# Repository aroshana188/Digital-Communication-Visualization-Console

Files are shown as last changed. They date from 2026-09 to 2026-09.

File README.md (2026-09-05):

# Digital Communication Visualization Console





*An interactive embedded hardware instrument engineered to visually map and demonstrate the fundamental mathematical abstractions of digital communication pipelines.*

<p align="center">
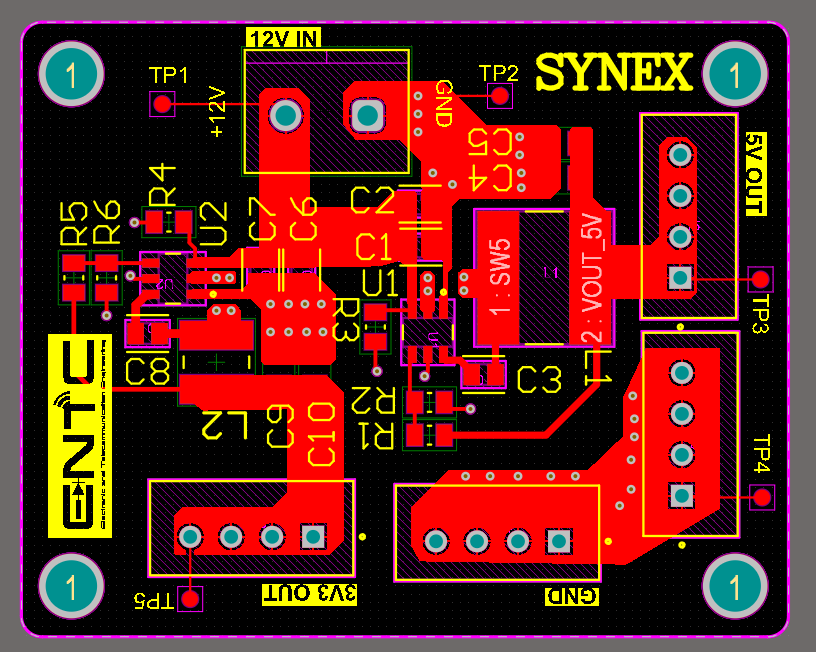
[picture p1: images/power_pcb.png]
  
</p>

---

## 📋 Project Overview
Developed by Team SyneX for the EN2160 Electronic Design Realization module, this desktop console solves a critical pedagogical gap in undergraduate telecommunication engineering. It provides a real-time, tactile hardware verification loop for abstract mathematical concepts like entropy reductions, cyclic redundancy protections, and complex constellation mappings.

Processing a user-defined alphabet set, the STM32-driven console dynamically renders multi-stage transformations—from Source Coding and Packetization to Channel Coding and Digital Modulation—directly onto dual 3.5" TFT panels and LED monitoring arrays.

---

## 🛠️ My Engineering & Business Contributions
As a core member of Team SyneX, I took ownership of the following technical and commercial domains:

### 1. Power Architecture & PCB Design
* **Dual-Buck Converter PCB:** Designed a dedicated power distribution PCB utilizing switching-mode buck converters to efficiently step down a 12V DC input to a stable 5V rail (for TFT displays/LEDs) and a clean 3.3V rail (for the STM32 logic).
* **Signal Integrity:** Implemented strict isolation strategies on a double-sided FR4 PCB, restricting high-speed SPI data traces to the top copper layer while isolating sensitive analog noise-simulation routing on the bottom layer, anchored by a solid ground pour to prevent EMI.

### 2. Mechanical Engineering & Enclosure CAD
* **Parametric Modeling:** Engineered the mechanical enclosure using SolidWorks, adopting a top-down assembly methodology. 
* **Ergonomics & Fabrication:** Designed optimized, reflection-free display mount angles for collaborative laboratory viewing. Integrated specialized internal mounting bosses for the PCBs and utilized equation-driven global variables to ensure dimensional coherence for eventual injection-molding scalability.

### 3. User Interface (UI) Architecture
* **Dual-Display Logic:** Contributed to the interface formatting layout across the twin 3.5" SPI TFT panels.
* **Tactile Integration:** Mapped the interface to allow users to input character strings via a 4x4 matrix keypad and visualize real-time bit error rate (BER) transformations dynamically controlled by a physical analog linear potentiometer.

### 4. Business Model & Market Analysis
* **Demand Forecasting:** Evaluated the Sri Lankan educational sector, identifying a potential market demand of 80 to 100 units across local universities and technical institutes.
* **Financial Procurement:** Calculated a scaled mass production budget, bringing the final market-ready cost down to LKR 25,425 per unit by strategizing bulk component sourcing and injection molding.
* **Commercialization Strategy:** Formulated a competitive B2B pricing strategy and Unique Value Proposition, positioning the console as a highly affordable, locally manufactured alternative to expensive imported telecommunication instrumentation platforms.

---

## ⚙️ System Specifications & Capabilities

### Hardware Core
* **Microcontroller:** STM32 ARM Cortex-M Series
* **Displays:** 2 x 3.5" SPI TFT Displays (320x480) driven via DMA
* **Bitstream Mapping:** 3x 74HC595 Serial-in Parallel-out Shift Register LED Arrays
* **Channel Simulation:** Analog Linear Rotational Potentiometer mapped to a 12-bit ADC

### Algorithmic Pipeline
1. **Source Coding:** Real-time generation of Fixed-Length, Huffman, and Shannon-Fano encoding trees.
2. **Packetization:** Dynamic segmentation of bitstreams into 4, 6, or 8-bit frame boundaries.
3. **Channel Coding:** Generation and verification of Parity (Even/Odd), CRC (CRC-3/CRC-4), and (7, 4) Hamming Code protection.
4. **Modulation:** Phase-mapping for ASK, BPSK, QPSK, and 16-QAM constellation rendering.

---

## 🤝 Team SyneX
This console was engineered by undergraduates at the Department of Electronic & Telecommunication Engineering, University of Moratuwa:
* **A.M.S. Ahamed**
* **H.A.P. Aroshana** *(Power PCB, Enclosure CAD, UI Design, Market Analysis)*
* **W.D.A.C. Bandara**
* **R.K.T. Dissanayake**
* **U.G.R.B. Tennakoon**

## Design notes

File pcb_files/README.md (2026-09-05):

This folder contains all circuit schematics and pcb files.

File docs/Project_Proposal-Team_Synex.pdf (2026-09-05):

# Digital Communication Visualization Console

## Project Proposal by Team Synex

Domain: Education, Telecommunications

### Problem Statement

Digital communication is a core subject in electrical and telecommunication engineering programs in Sri Lanka. However, most universities rely heavily on simulations (MAT-LAB/Python) to teach concepts such as source coding, packetization, CRC, and channel errors.
Students often understand mathematical theory but struggle to visualize:
- How variable-length coding compresses data
- How packets are formed
- How CRC bits are generated
- How noise corrupts bits
- How corrupted packets are detected and discarded

Therefore, there is a need for an affordable, locally developed, hardware-based communication system demonstrator that visually represents each stage of a digital communication chain.

### Stakeholder Analysis

Primary Stakeholders

- State universities offering Telecommunication degrees
- Private engineering institutions
- Technical and vocational training institutes
- Institutions such as University of Moratuwa and University of Peradeniya conduct communication systems laboratories where this device can be directly deployed

Secondary Stakeholders

- Lecturers who require demonstrative teaching tools
- Undergraduate students learning digital communications
- Lab coordinators managing equipment budgets

Stakeholder Insights

Stakeholders Consulted - Dr.Samiru Gayan, Senior Lecturer, Electronic and Telecommunications Department, University of Moratuwa.

During preliminary discussions with Dr. Samiru Gayan, it was highlighted that current laboratory sessions rely heavily on simulations. Although simulations are useful, they do not provide a clear physical representation of:

EN2160 - Electronic Design Realization | Team Synex
- Bitstream formation
- Packet boundaries
- Redundancy addition
- Bit corruption due to noise
- Packet rejection mechanisms

### Proposed Solution

The Digital Communication Visualization Console (DCVC) is a desktop unit that demonstrates:

- Symbol generation
- Fixed-length and Huffman source coding
- Packetization (4–8 bit packets)
- Parity and CRC error detection
- Adjustable noisy channel
- Packet validation and rejection

Users can enter short messages, observe LED-displayed codewords, divide the bitstream into small packets (4, 6, or 8 bits), add CRC/parity bits, transmit through a simulated noisy channel, and observe accepted or rejected packets.

### Technical Specifications

Parameter | Specification
Symbols | 5 (A–E)
Coding Methods | Fixed (3-bit), Huffman
Packet Sizes | 4, 6, 8 bits
Error Detection | Even/Odd Parity, CRC
CRC Divisor | 3–4 bit user input
Noise Model | Adjustable BER
Controller | ESP32
Display | 2.4” TFT LCD
Bit Visualization | 8–16 LED array
Power Supply | 5V DC

Table 1: DCVC Technical Specifications

EN2160 - Electronic Design Realization | Team Synex

### Budget Estimation

Category | Item | Total (LKR)
Microcontroller | ESP32 | 1,000
Display | 2.4” TFT LCD | 1,700
LED Arrays & Drivers | 74HC595 + LEDs | 3,500
Input Controls | Push Buttons, Encoder, DIP Switches | 2,500
Power & Regulation | 5V Supply, Regulators | 2,500
PCB Fabrication | 2-layer PCB | 5,000
Enclosure | Acrylic/ABS casing | 5,000
Miscellaneous | Wiring, Connectors, Mounting | 3,000
Estimated Total | | 24,200

Table 2: DCVC Budget Breakdown

According to this approximation, the total cost per unit is around LKR 25,000. The expected selling price could be LKR 30,000–35,000.

### Hardware and Software Complexity

The system consists of four main subsystems:

- Input Subsystem – Push buttons (A–E), probability adjustment knob, packet size selector, CRC divisor input.
- Processing Subsystem – ESP32 microcontroller implementing: Huffman tree generation, Fixed-length coding, Packetization, CRC computation, Pseudo-random noise injection.
- Visualization Subsystem – LED arrays for codewords and packet bits, TFT display for packet view.
- Control & Power Subsystem – Voltage regulation, LED driver circuits, protection components.

### Estimated Market Requirement in Sri Lanka

Estimated institutions:

- ≈10 universities with engineering programs,
- ≈20 technical institutes

Assuming:

- 4–5 units per university,
- 2–3 units per technical institute

Total potential demand ≈ 80–100 units
Estimated annual demand ≈ 15–25 units
This makes the product commercially viable within the educational sector.

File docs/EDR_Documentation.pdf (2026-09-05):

### University of Moratuwa

### Faculty of Engineering

### Department of Electronic & Telecommunication Engineering

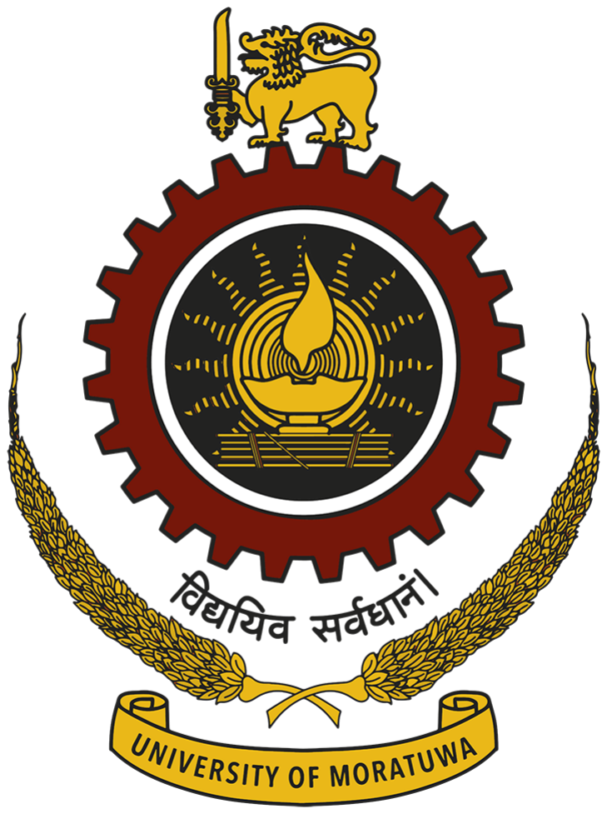
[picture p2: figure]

### EN2160: Electronic Design Realization

# Digital Communication Visualization Console

### An Interactive Embedded System for Visualizing Fundamental Concepts of Digital Communication Systems

### Team SyneX

230020R A.M.S. Ahamed
230058N H.A.P. Aroshana
230082G W.D.A.C. Bandara
230164K R.K.T. Dissanayake 230629R U.G.R.B. Tennakoon

Abstract

Abstract mathematical paradigms in telecommunication engineering, including variable-length source entropy reductions, linear block cyclic redundancy protections, and complex constellation symbol mappings, present significant pedagogical barriers in traditional undergraduate lecturing formats. This report documents the complete design realization of the Digital Communication Visualization Console by Team Synex for module EN2160. Driven by a high-performance ARM Cortex-M based STM32 microcontroller, this hardware instrument provides a localized physical verification loop for abstract concepts. Processing a user-defined alphabet set (S = {A, B, C, D, E}), the console calculates and renders multi-stage transformations—from Source Coding (Fixed-length, Huffman, Shannon-Fano) to Packetization framing configurations, Channel Coding (Parity, CRC, Hamming), and digital modulations (ASK, BPSK, QPSK, QAM). Featuring twin 3.5” SPI TFT panels managed via Direct Memory Access (DMA), dynamic 74HC595 shift reg-

ister LED monitoring arrays, and physical potentiometer-driven additive noise emulation circuits interfacing with internal 12-bit ADCs, the device allows students to visually audit transmission metrics, code-word transitions, and real-time constellation degradation.

# Contents

Digital Communication Visualization Console | University of Moratuwa
8.2 | Potentiometer Noise Calibration and Signal Profile Mapping . . . | 14
11.2 | Real-Time Bit Error Rate (BER) Graphical Plotting Engine . . . | 19

# List of Figures

1 | Global Block Interconnect Architecture and STM32 Bus Distribution . . | 6
2 | Enter Caption | | 6
3 | Enclosure Mechanical Evolution and Interface Formatting Layout . . . . | 12
4 | Central STM32 System Schematic and Bus Track Routing Breakouts . . | 13
5 | 12V to 5V and 3.3V Dual Buck Converter Power Schematic | | 13

# List of Tables

1 | Design Matrix of Architectural Implementation Alternatives | | 7
2 | System Hardware and Architectural Component Specifications | | 8
3 | Algorithmic Compression and Code-Word Length Test Matrix | | 14
4 | STM32 12-bit ADC Noise Mapping Calibration Data | | 15
5 | Itemized Component Budget for the Initial Prototype | | 16
6 | Estimated Unit Budget for Scaled Production (100–200 Units/Year) . . . | 17

### 1 Introduction

### 1.1 Background

Modern telecommunication systems rely on multi stage digital signal manipulation architectures to maximize data transfer rates, minimize operational bandwidth utilization, and defend information vectors against channel impairments. In pedagogical frameworks, these multi stage blocks are fundamentally decoupled into strict mathematical abstractions: informational entropy metrics, orthogonal phase space projections. While critical for core engineering theory, these mathematical concepts frequently present comprehension challenges for undergraduate students when separated from tactile, real time hardware manifestations.

### 1.2 Motivation

The inspiration for this design is rooted in the current educational gap within electrical and telecommunication laboratory courses in Sri Lanka. Engineering students typically evaluate communication pipelines via pure software simulation scripts (e.g., MATLAB or Python environments). Although software environments offer numerical flexibility, they

separate students from physical timing restrictions, real time clock domains, and hardware interface realities. This project establishes an interactive, intermediate educational desktop platform that delivers high fidelity visual and tactile feedback in real time.

### 1.3 Problem Statement

Digital communication is a cornerstone domain within electrical, electronic, and computer engineering curricula. However, undergraduate engineering students often master the underlying abstract mathematical frameworks while struggling to build a clear mental model of physical realization. Specifically, students struggle to visualize:

- The operational behavior and code-tree generation variations of dynamic variable-

length source compilers.

- How bitstreams are partitioned into distinct boundaries to execute packetization

workflows.

- How redundancy bits (CRC or parity) are mathematically appended to message

frames.

- The explicit mechanism by which random channel noise corrupts transmission bits.
- How corrupted packets are evaluated, flags are trigged, and bad frames are ulti-

mately rejected and discarded by receiver logic.

### 1.4 Stakeholder Analysis

To map the deployment environment effectively, a complete stakeholder analysis was executed:

- Primary Stakeholders: State and private engineering universities offering Telecom-

munication, Electronic, and Electrical Engineering degree programs (such as the University of Moratuwa and the University of Peradeniya). This also includes tech-

nical, vocational, and technological colleges where communication systems laboratories require practical instrumentation benches.

- Secondary Stakeholders: Academic lecturers and instructors who require real

time demonstrative teaching aids, undergraduate students seeking intuition beyond math equations, and lab coordinators managing tight equipment procurement budgets.

### 1.5 Stakeholder Insights & Expert Consultation

Detailed consultation loops were conducted with Dr. Samiru Gayan, Senior Lecturer within the Department of Electronic & Telecommunication Engineering at the University of Moratuwa. Dr. Gayan confirmed that current university laboratory exercises are structurally skewed toward abstract software models. He emphasized that the introduction of a localized hardware development platform would resolve critical learning bottlenecks by providing immediate visual indicators for bitstream formation, packet boundaries, redundancy additions, and hardware packet rejection behaviors.

### 1.6 Project Objectives

The system targets the following core engineering goals:

- Construct a robust, standalone laboratory instrument that processes a standard

data alphabet set (S = {A, B, C, D, E}) under user specified statistical profiles.

- Integrate a continuous software execution pipeline comprising interchangeable algo-

rithmic blocks for Source Coding, Packetization framing, Channel Error Protection, and Carrier Modulation.

- Implement a dual display SPI processing topology utilizing STM32 DMA controllers

to separate operational menu entry tracking from physical wave shape and constellation scatter layouts.

- Deploy a tactile hardware subsystem utilizing automated logic registers and analog

noise pots to show bit error rate transformations dynamically.

### 1.7 System Scope & Boundaries

The console serves strictly as a baseband and digital carrier visualization instrument for academic laboratories. The hardware boundary focuses on structural logic validation and display rendering rather than high power RF transmission over antennae arrays. All signal mutations, carrier shapes, and channel path interference distributions are mapped directly within the core microcontroller logic engine and translated to dedicated visual interfaces.

### 2 System Architecture & Engineering Alternatives

### 2.1 Global Block Interconnect Architecture

The structural framework of the system relies on a modular, decoupled signal routing layout. High level compute blocks pass operational parameters directly to localized peripheral hardware layers.

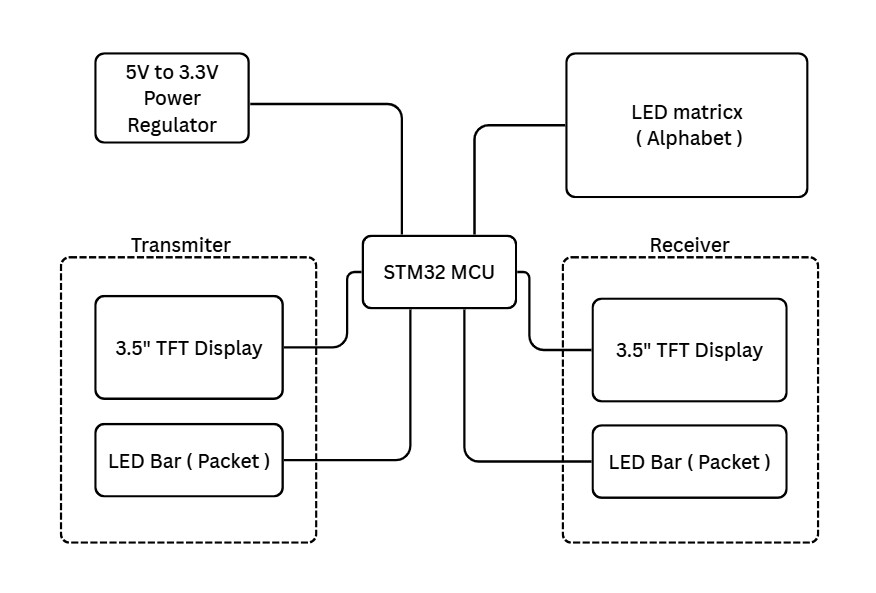
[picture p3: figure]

Figure 1: Global Block Interconnect Architecture and STM32 Bus Distribution

Figure 2: Enter Caption

### 2.2 Analysis of System Engineering Alternatives

During the conceptualization phase, three architectural implementations were evaluated. Table 1 summarizes the comparative trade offs that informed the final hardware selection.

Table 1: Design Matrix of Architectural Implementation Alternatives

Implementation
Path
Engineering Advantages | Technical Disadvantages

Pure Software
Simulation
(MATLAB /
Python)

High mathematical precision; easy implementation architectures; zero physical development limitations.

No tactile user interactions;
completely | separated | from
physical clock domains or hardware timing limits; zero real time interaction loops.

FPGA
Hardware
Platform
Parallel | processing; | sub-
nanosecond | clock | matching;
native signal generation speed.

High development overhead; complex HDL debug tracks;
long compile cycles; expensive development boards.

STM32 ARM
Cortex Microcontroller
Hardware | level | DMA, | na-
tive nesting vector interrupts (NVIC), rich configuration of independent SPI peripherals, predictable real-time execution.

Finite parallel graphics rendering lanes compared to FPGAs (mitigated by optimized DMA display buffering).

### 3 Detailed Requirement Analysis & System Specifications

### 3.1 Functional Requirements

The hardware and software design layout must strictly execute five sequential signal operations.

1. Tactile User Input Mapping: Monitor an integrated physical matrix keypad to capture character strings from the asset alphabet (S = {A, B, C, D, E}), and

capture user defined probability values through an interactive menu.

2. Source Compression Compiling: Run real time binary string generation using 3-bit Fixed Length formats, Variable Length Huffman encoding structures, and Shannon Fano splitting trees.
3. Dynamic Packetization Framing: Segment structural source bitstreams into distinct, user selectable frame boundaries.
4. Channel Protection Processing: Generate and inject mathematical parity configurations (Even/Odd options), Cyclic Redundancy Check (CRC-3/CRC-4 via 3-bit or 4-bit user-selected generator inputs)
5. Modulation Phase Mapping: Map generated bitstreams into discrete complex carrier vectors supporting Amplitude Shift Keying (ASK), Binary Phase Shift Keying (BPSK), Quadrature Phase Shift Keying (QPSK), and 16-Quadrature Amplitude Modulation (16-QAM).

### 3.2 Non-Functional Requirements

- UI Latency Limitations: Frame updates across the dual-display TFT panels

must sustain a minimum target of 30 frames per second (FPS), ensuring real-time

responsiveness when modulating carrier graphs.

- Structural Durability: The mechanical enclosure must safely support continuous

laboratory use inside university environments without thermal throttling or loose electrical junctions.

- User Accessibility: The interface layout must be intuitive for engineering under-

graduates, featuring immediate menu execution links and physical control dials.

### 3.3 System Specifications Matrix

Table 2 lists the functional components and hardware interfaces used in the design.

Table 2: System Hardware and Architectural Component Specifications

System Parameter
Domain

Target Implementation Element

Central Microcontroller | STM32 ARM Cortex-M Series (32-bit Architecture)
Primary Graphical Panels | 2×3.5 ′′ SPI Thin-Film-Transistor (TFT) Displays (320× 480)
Bitstream Mapping Displays | 3× 74HC595 Serial-in Parallel-out Shift Register LED Arrays
User Input Device | 4 × 4 Matrix Tactile Keypad
Channel Interference Control | 1× Analog Linear Rotational Potentiometer
Power Supply Rail | Integrated 5V to 3.3V Low Dropout (LDO) Regulator Infrastructure

### 4 Hardware Realization & Electronic Circuit Design

### 4.1 Central Microcontroller Infrastructure (STM32)

The processing topology leverages the nested hardware vector architecture of an STM32 microchip. Processing routines are timed explicitly using an integrated Real-Time Operating System (RTOS) or bare-metal interrupt scheduling:

- Core Communication Pipeline: Executes keypad matrix debounce scans, state-

machine switches, mathematical code-tree processing, packet framing isolation, and phase coordinate generation.

- Graphics Multi-Buffering Engine: Offloads frame-buffer arrays via dedicated

STM32 DMA streams to the SPI lines, allowing zero-overhead pixel rendering.

### 4.2 Dual-Display SPI Interfacing Logic

To present operational menus alongside real-time carrier waveforms without causing bus contention or screen tearing, the display layout utilizes separate hardware SPI blocks (e.g., SPI1 and SPI2) on the STM32.

### 4.3 Serial Shift Register Bit-Array LED Monitoring Matrix

To display high-density binary streams at discrete processing points (Source output vs. Channel output) without consuming scarce MCU GPIO pins, three 74HC595 shift regis-

ters are cascaded. This allows the system to update 30 unique LED indicators using just 3 processor pins via synchronous latch clocked bursts.

### 4.4 Analog Channel Noise Simulation Circuit

The analog channel emulation stage maps physical user adjustments directly to digital noise generation models. A linear potentiometer provides an adjustable voltage vector across an internal STM32 12-bit ADC channel. The measured value sets the standard deviation σ within the firmware noise algorithm, driving an adjustable Bit Error Rate (BER) output layout:

VADC Input =

Rpot wiper

Rtotal track
- VDD 3.3 | (1)

### 5 Mathematical Formulations & Algorithmic Design

### 5.1 Source Coding Frameworks

The asset alphabet processing engine tracks input structures across a standardized symbol library:
S = {A, B, C, D, E} subject to X

i∈S

P(i) = 1.0 | (2)

Huffman Coding Engine

The compression module builds a dynamic binary tree sorted by descending token weights. Codewords are generated recursively by tracing binary paths from the root node down to the individual character leaves.

Shannon-Fano Compression Logic

The alphabet tokens are sorted by descending probability and bisected into matching subsets to equalize the cumulative probability densities across each branch. A ’0’ binary bit is assigned to the upper partition and a ’1’ binary bit to the lower partition. This logic repeats recursively until every leaf node is isolated.

### 5.2 Channel Coding Verification Matrix

Cyclic Redundancy Check (CRC-3 / CRC-4)

The cyclic division block utilizes a software shift register verification framework. The system divides the expanded message block Xn
·M(X) by a user-selected generator polynomial G(X) (supporting both 3-bit and 4-bit polynomial inputs configured via software menu loops) using bitwise XOR operations to determine the trailing validation bits R(X):

R(X) = Remainder

Xn
- M(X)
G(X)
(3)

Linear Block Hamming Code Protection

The system implements a (7, 4) systematic Hamming single-error correction matrix. Mes-

sage nibbles are mapped to standard block positions, and parity elements are computed at power-of-two index coordinates (1, 2, 4). At the receiver block, error vectors are isolated

via matrix syndrome checks:
S = H · YT
(4)

If the calculated syndrome vector S ̸= 0, the system pinpoints the flipped bit position,

corrects it automatically, and triggers a localized indicator LED on the console.

### 5.3 Packet Validation and Rejection Mechanics

When packet structures run with injected noise anomalies, the receiver subsystem conducts automated parity check comparisons and structural CRC recalculations. If the computed remainder fields or parity parity sums yield alignment failures against the transmitted payload headers, the active TFT display marks the corresponding packet frame as **Rejected**, discarding the corrupted array and incrementing an onboard

real-time dropped-packet tally.

### 5.4 Digital Carrier Modulation Phase-Mapping

The digital mapping core transforms binary frames into discrete, high-frequency mathematical vectors in phase-space:

sBPSK(t) = A cos
2πfct + π · bk
bk ∈ {0, 1} | (5)

sQPSK(t) = A cos
2πfct +

(2m + 1)π
4
m ∈ {0, 1, 2, 3} | (6)
s16QAM(t) = Ik cos(2πfct) − Qk sin(2πfct) Ik, Qk ∈ {−3, −1, 1, 3} | (7)

### 6 Enclosure Architecture & Mechanical Design

### 6.1 Design Constraints & Material Selection

The mechanical enclosure balances long term structural stability. The high impact Polylactic Acid (PLA) polymers were chosen for the body shell to minimize total tool weight

while providing adequate structural rigidity. We use a optimal infill rate to achieve the optimal balance between cost and strength. The clear structural windows are integrated across the display faces to preserve access to tactile controls. The heat management considerations were also integrated directly into the spatial layout to ensure adequate passive cooling for the internal power regulation circuitry.

### 6.2 Mechanical CAD Design Evolution

The mechanical architecture transitioned through multiple parametric CAD iterations, driven primarily by a philosophy of human centric design to prioritize user interaction and desktop ergonomics. The display mount angles were specifically re-engineered to provide an optimized, reflection free viewing axis for collaborating laboratory teams. Beyond interface ergonomics, the geometric evolution carefully balanced physical stability on the workbench, a professional aesthetic appearance of a laboratory equipment, and strict material cost constraints, ensuring the final enclosure is both highly functional and economical to fabricate.

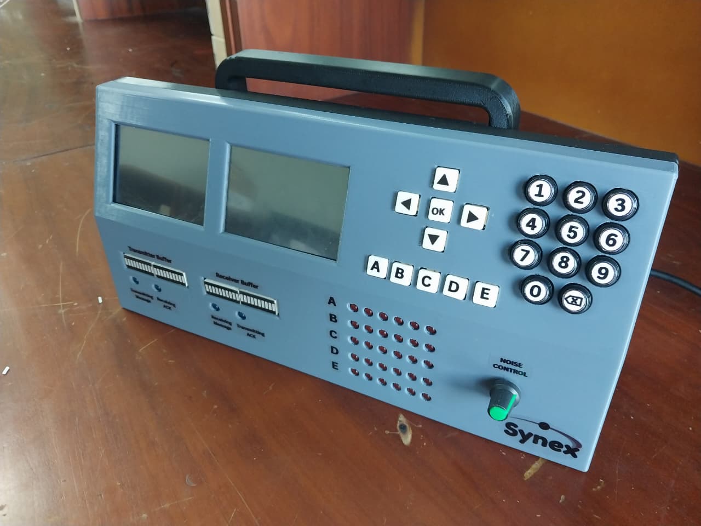
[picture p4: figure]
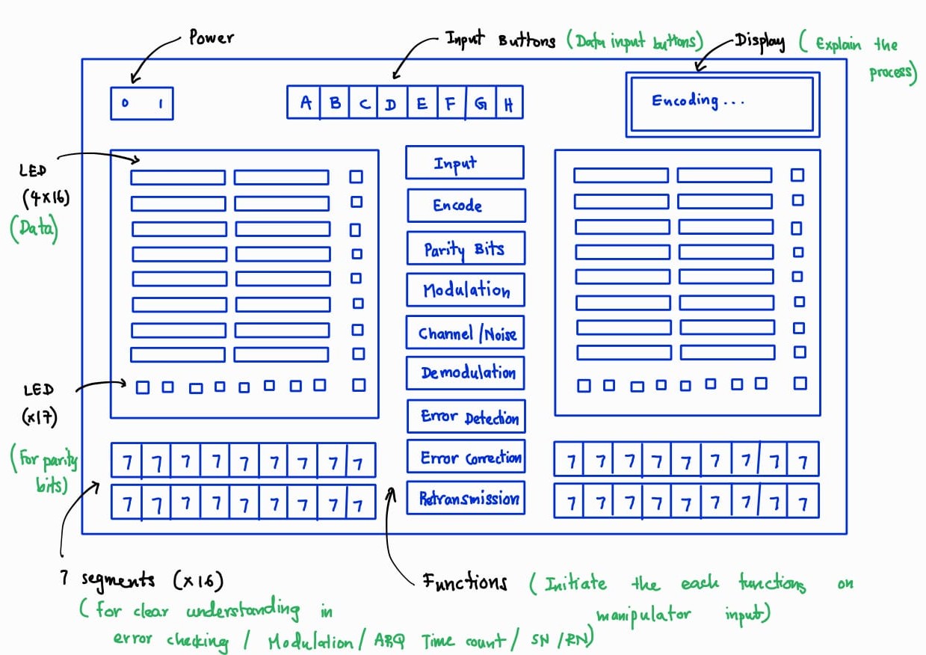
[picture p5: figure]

(a) Initial Layout (Sketched Layout) | (b) Finalized CAD Render Model

Figure 3: Enclosure Mechanical Evolution and Interface Formatting Layout

### 6.3 Professional CAD Methodologies & Skill Application

The mechanical development phase was executed using SolidWorks, an industry standard 3D CAD software suite. To ensure dimensional coherence across all mating components, a top down assembly modeling approach was adopted. This methodology allowed the enclosure to be conceptualized and scaled as a single, unified structure before being partitioned into distinct manufacturable bodies.
To maximize design flexibility and reflect professional engineering practices, the model was constructed using equation driven parametric dimensions governed by a master configuration of global variables. This ensured that any adjustments to display clearances or internal PCB footprints automatically cascaded through the entire mechanical assembly. Furthermore, advanced CAD tools were utilized to implement robust structural elements, specialized internal mounting bosses to securely anchor the hardware.

### 7 PCB Layout Architecture & Isolation Strategies

### 7.1 Electrical Schematic Design Topology

The electronic design uses a modular hardware topology to improve system reliability. The physical layout is divided into two primary printed circuit boards (PCBs).

The first board is a dedicated power supply PCB. This board handles voltage regulation and safely distributes stable power to the rest of the system. The second board is the centralized MCU PCB. It hosts the main STM32 microcontroller and acts as the brain of the console.
All external input and output peripherals, such as the TFT displays and the keypad, connect directly to this central MCU board. We utilize standard JST connectors for these peripheral links. This modular approach makes the physical assembly much easier. Furthermore, it cleanly isolates the sensitive high-speed digital data paths from the main power circuits.

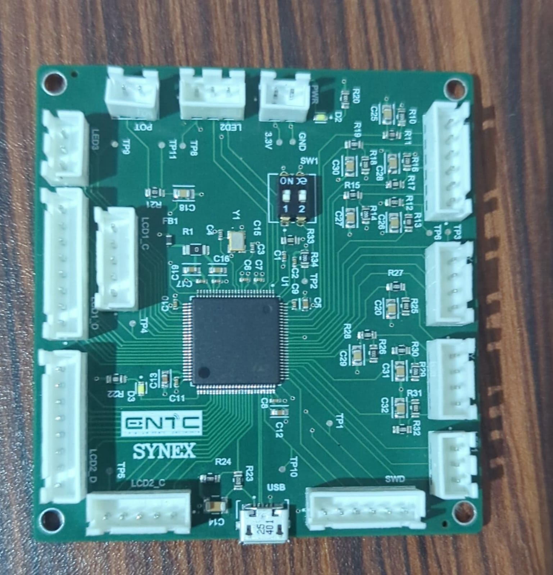
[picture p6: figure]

Figure 4: Central STM32 System Schematic and Bus Track Routing Breakouts

### 7.2 Power Supply & Voltage Regulation PCB

The system receives a standard 12V DC input from an external laboratory power supply dock. To handle this input efficiently, we developed a dedicated power distribution PCB. Instead of using traditional linear regulators, this board utilizes switching mode buck converter ICs to maximize power efficiency and reduce heat generation.
We designed two separate step down conversion circuits on this board. The first buck converter drops the 12V input down to a stable 5V rail. This 5V supply is exclusively routed to drive the power hungry components, specifically the dual TFT displays and the LED monitoring arrays. The second buck converter steps the voltage down to a clean 3.3V rail. This 3.3V supply safely powers the main STM32 microcontroller and the remaining digital logic circuits.
By utilizing switching mode ICs for both conversion stages, the system achieves significantly higher overall power efficiency (more than 85%). This ensures the console remains

cool and stable during continuous laboratory operation.

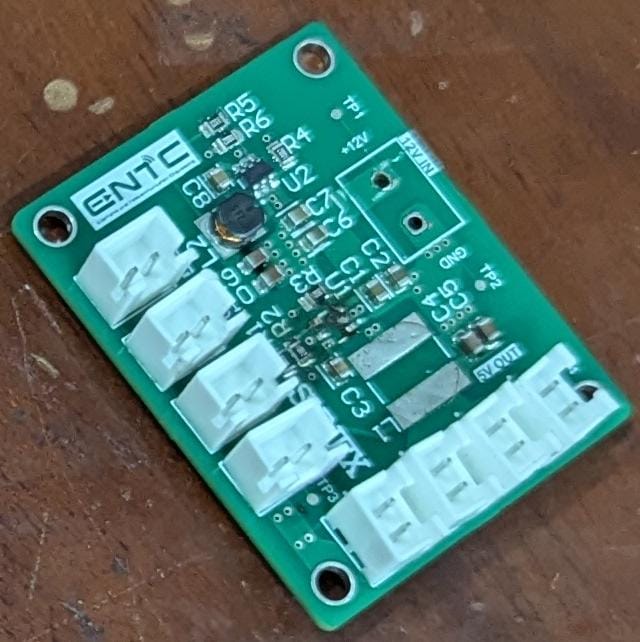
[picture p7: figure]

Figure 5: 12V to 5V and 3.3V Dual Buck Converter Power Schematic

### 7.3 PCB Layer Optimization & Signal Integrity

We fabricated the main board using a standard double sided FR4 printed circuit board. The board features a 1.6 mm thickness and a 1 oz copper weight.
To maintain strict signal integrity, we completely isolated the digital and analog routing paths. All high-speed SPI data traces are routed exclusively on the top copper layer. Conversely, the sensitive analog routing for the noise simulation is restricted to the bottom layer. This physical separation prevents digital crosstalk from corrupting the analog signals.
Furthermore, we implemented a solid, unbroken ground plane across the bottom layer. This extensive ground pour provides a low impedance return path for all circuits. It is highly effective at preventing ground loops and minimizing high frequency electromagnetic interference (EMI).

### 8 Testing, Verification & Experimental Calibration Results

### 8.1 Algorithmic Verification Parameters

To evaluate the compression engine, variable-length source profiles were validated using a standard test sequence string (AABACAE). The experimental performance results are

summarized in Table 3.

Table 3: Algorithmic Compression and Code-Word Length Test Matrix

Input Profile Vector Coding Mode | Resulting Bits Entropy Factor
AABACAE | Fixed-Length Base | 21 Bits | 1.0000
AABACAE | Huffman Engine | 13 Bits | 0.6190
AABACAE | Shannon-Fano Mode | 14 Bits | 0.6667

### 8.2 Potentiometer Noise Calibration and Signal Profile Mapping

The analog noise emulation stage was calibrated using an external digital storage oscilloscope. The relationship between physical control dial position, raw internal 12-bit STM32 ADC register tracking values (0 to 4095), and the generated peak-to-peak voltage noise

envelope is documented in Table 4.

Table 4: STM32 12-bit ADC Noise Mapping Calibration Data

Rotational Angle (

◦
) | Measured 12-bit ADC
| Register | Calculated Output σ
| | Voltage (Vp-p)
0 (Minimum Limit) | 0x000 | 0.00 V
45 | 0x249 | 0.15 V
90 | 0x492 | 0.32 V
135 | 0x6DB | 0.48 V
180 (Midpoint) | 0x924 | 0.65 V
225 | 0xB6D | 0.82 V
270 (Maximum Limit) | 0xFFF | 1.20 V

### 9 Financial Procurement Analysis & Scaled Cost Budgeting

### 9.1 Prototyping Bill of Materials (BOM)

This section details the hardware expenditure required to build the initial laboratory prototype of the console. The total development cost reflects small volume retail pricing for individual components rather than bulk rates. Table 5 provides a complete itemized breakdown of these expenses.

Table 5: Itemized Component Budget for the Initial Prototype

Component
Description

Unit Price (LKR) No. of Units Final Cost (LKR)

STM32 ARM Cortex
MCU
| 2,200 | 1 | 2,200
3.5” SPI TFT Graphic Display Modules | 2,750 | 2 | 5,500
74HC595 Logic Shift Registers | 50 | 3 | 150
High-Intensity Indicator LEDs | 3 | 25 | 75
LED Light Bars | 50 | 4 | 200
4×4 Matrix Tactile Keypad | 1,200 | 1 | 1,200
Linear Analog Potentiometer Dial | 50 | 1 | 50
Double-Sided FR4 Custom PCB Fabrication | 3,500 | 1 | 3,500

Custom 3D Printed
Mechanical Enclosure
Shell
23,000 | 1 | 23,000

Passive Support
Components (LCSC)
| 3,500 | 1 | 3,500
Logistics | 2,450 | 1 | 2,450
12V Power Adapter | 1,775 | 1 | 1,775
Total Prototyping Budget | | | LKR 43,600

### 9.2 Mass Production & Scaled Cost Budgeting

This section forecasts the unit cost when scaling production to an estimated 100 to 200 units per year. Sourcing components in bulk directly cuts the individual component prices.
First, the custom PCB fabrication cost drops significantly because the initial setup fees are divided across many boards. Second, importing electronic components in bulk batches drastically reduces the unit purchasing rates and shipping overhead. Finally, shifting from single unit 3D printing to low-volume injection molding reduces the enclosure cost once the initial mold cost is distributed across the production run. Table 6 summarizes these optimized manufacturing costs per unit.

Table 6: Estimated Unit Budget for Scaled Production (100–200 Units/Year)

Component
Description

Unit Price (LKR) No. of Units Final Cost (LKR)

STM32 ARM Cortex
MCU Module
1,600 | 1 | 1,600

3.5” SPI TFT Graphic
Display Modules
2,350 | 2 | 4,700

4×4 Matrix Tactile
Keypad
850 | 1 | 850

Double-Sided FR4
Custom PCB
Fabrication
600 | 1 | 600

Scaled
Injection-Molded
Mechanical Enclosure
9,900 | 1 | 9,900

Passive Support
Components (LCSC)
| 3,150 | 1 | 3,150
12V Power Adapter | 975 | 1 | 975
Total Scaled Unit Budget | | | LKR 21,775

### 9.3 Final Production Cost

The raw component budget does not reflect the complete price of the product. To calculate the true final production cost per unit, we must include several manufacturing overheads.
The following additional costs are considered for the mass production phase.
- Assembly and Labor Costs (LKR 450): Expenses for automated PCB assem-

bly (Pick-and-Place) and manual soldering of larger components.

- Testing and Quality Assurance (LKR 950): The cost of functional testing,

hardware calibration, and defect inspection for each unit.

- Packaging and Logistics (LKR 600): Expenses for protective foam packaging,

printed user manuals, and institutional shipping.

- Legal and Certification Fees (LKR 450): The distributed costs for safety

certifications, university tender documentation, and intellectual property filings.

- Warranty and Support Buffer (LKR 1200): A small reserve fund allocated

per unit to cover potential hardware replacements or future technical support.

By adding these manufacturing overheads (LKR 3,650) to our scaled unit component budget (LKR 21,775), we determine the final market-ready cost.

Final Mass Production Cost Per Unit: LKR 25,425

### 10 Business Model & Market Viability

### 10.1 Market Analysis & Targeted Implementations

Commercial telecommunication laboratory instrumentation platforms are typically imported from international markets, with procurement costs often reaching several million LKR per unit. This pricing model creates significant budgetary constraints for public and private engineering faculties in developing economies. The console bridges this gap by targeting:

- Government and private university electronic and telecommunication engineering

laboratories.

- Regional technical colleges and vocational training institutes.
- Advanced secondary school STEM training facilities.

### 10.2 Unique Value Proposition

- Integrated Multi-Stage Pipeline: Combines source encoding, packetization con-

straints, channel error correction, and high order modulation schemes into a single standalone platform.

- Tacitly Immersed Interface: Replaces purely virtual software environments with

physical potentiometer-driven noise injectors and diagnostic monitoring LEDs.

- Significant Cost Advantage: Delivers a standalone laboratory instrument at a pro-

duction price point that enables higher student-to-bench density ratios.

### 10.3 Commercialization and Sales Strategy

Our commercial strategy focuses on clear revenue streams and accessible customer channels.

- Revenue Model: Our primary profit earning method is direct sales. We are

mainly focusing on the Business-to-Business (B2B) market, targeting universities

and technical institutes. However, we are also open to the Business-to-Consumer (B2C) market for individual engineering students and hobbyists.

- Primary Online Portal: We will develop a dedicated official website. This web-

site will act as the main communication bridge between our team and the customers. It will handle direct order placements, customer support, and digital user manuals.

- Local Retail Partnerships: To increase our physical market presence, we plan

to collaborate with well-known electronic equipment shops across Sri Lanka. These local retail stores will accept customer orders and help us reach a wider audience.

- Pricing Strategy: Based on our final mass production cost of LKR 25,425, we

can set a competitive market price. A suggested retail price of LKR 59,000 to LKR 65,000 provides a strong profit margin of 135% while remaining highly affordable

for local engineering faculties.

### 11 Future Technical Expansion Tracks

### 11.1 Hardware-Defined Radio Sub-System Mixers

Future iterations will introduce an optional analog RF up-conversion stage. Integrating a high-speed Software-Defined Radio (SDR) I/Q mixer sub-board would allow the con-

sole’s digital baseband modulation waveforms to be transmitted over physical ISM radio frequencies (e.g., 2.4 GHz), creating an end-to-end physical wireless testing platform.

### 11.2 Real-Time Bit Error Rate (BER) Graphical Plotting Engine

An upcoming software update will introduce an automated, long-term testing routine. This module will systematically adjust the analog noise floor to construct and render real-time Waterfall and BER vs. Eb/N0 curves directly onto the auxiliary graphics display.

### 12 Project Conclusion

The Digital Communication Visualization Console successfully meets the technical design requirements established for module EN2160. By implementing source compression models, packet framing constraints, block error control coding, and high-order phase modulation on an optimized STM32 architecture, Team Synex has developed a robust educational laboratory instrument. This platform moves beyond static theoretical lectures and complex FPGA programming, providing engineering undergraduates with a tactile, real-time tool to bridge theory and practice. The production, cost, and design analyses demonstrate high implementation readiness for integration into undergraduate laboratories at the University of Moratuwa.

# Bibliography

[1] Digital | Communication | Visualization | Console. | GitHub | Repository,
2026. | [Online]. | Available: | https://github.com/Achintha-Bandara/

Digital-Communication-Vizualization-Console.git. (https://github.com/Achintha-Bandara/Digital-Communication-Vizualization-Console.git)

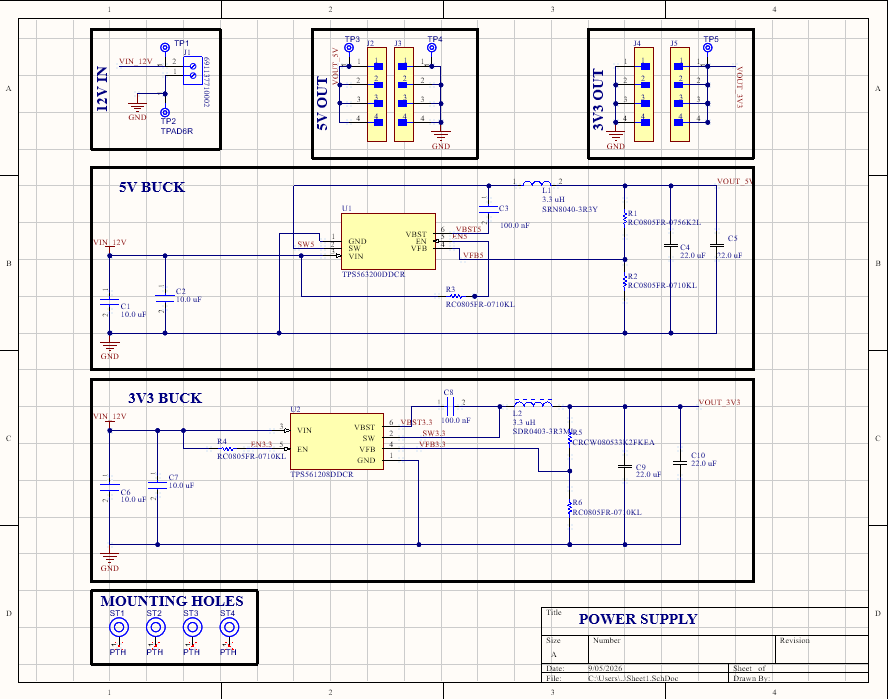
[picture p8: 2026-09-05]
images/power_pcb_schematic.png

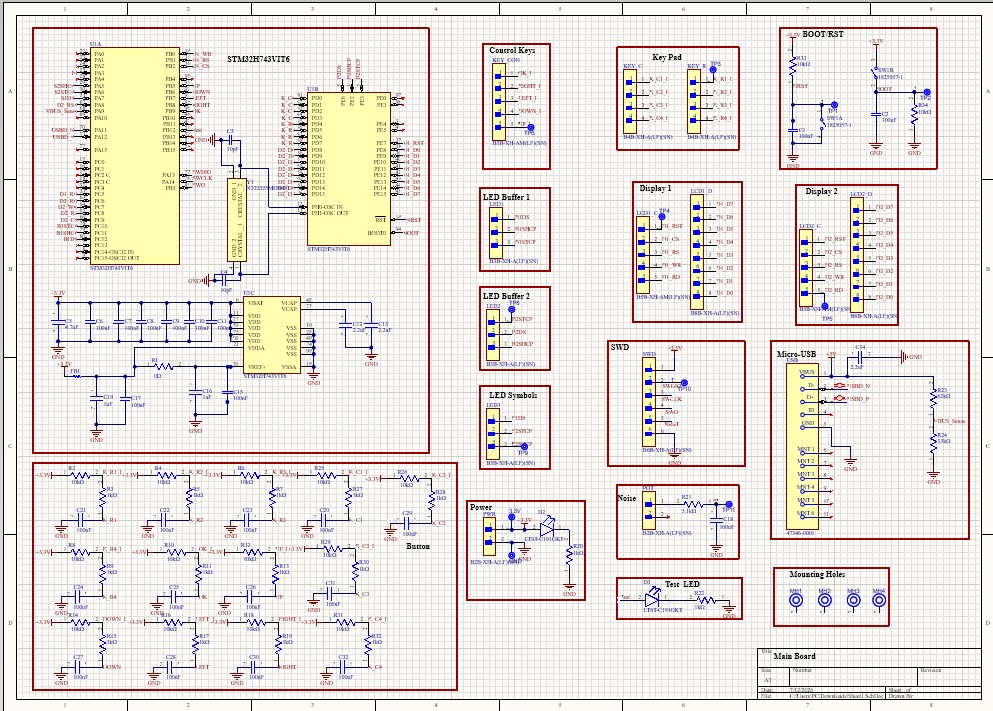
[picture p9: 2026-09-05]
images/mcu_sch.jpg

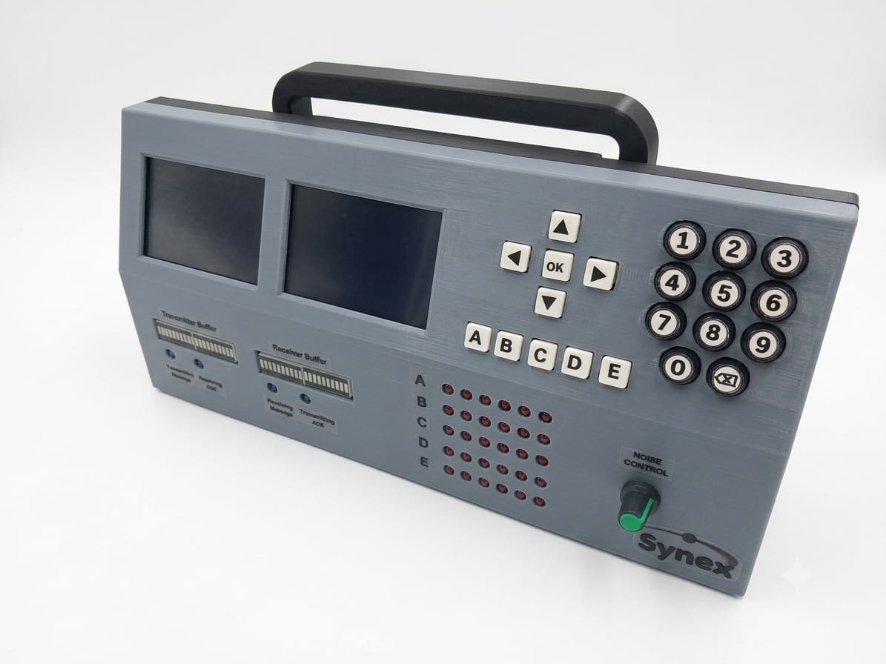
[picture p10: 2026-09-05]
images/final_product.jpeg

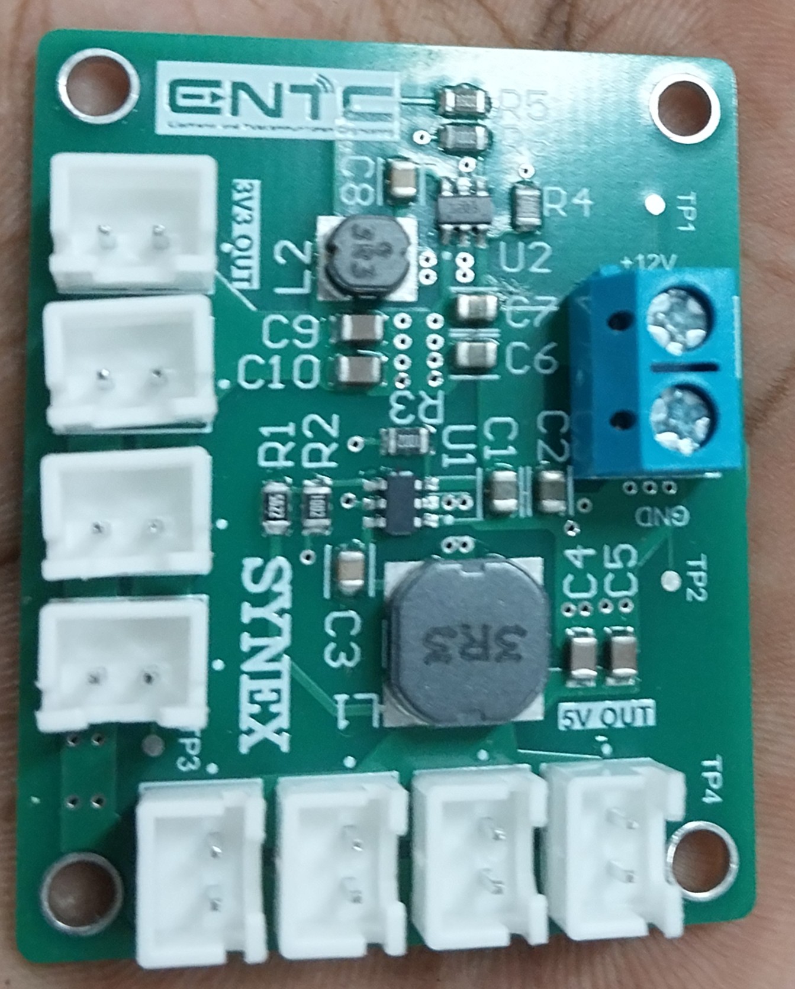
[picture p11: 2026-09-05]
images/power_pcb.jpg

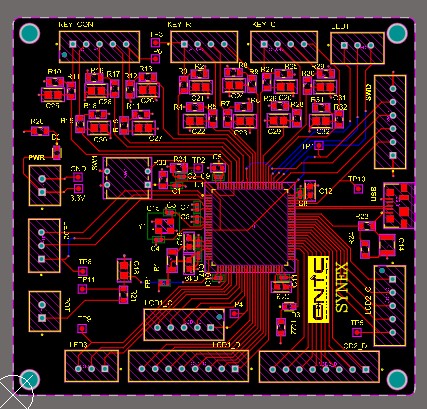
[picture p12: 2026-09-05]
images/mcu_pcb.jpg

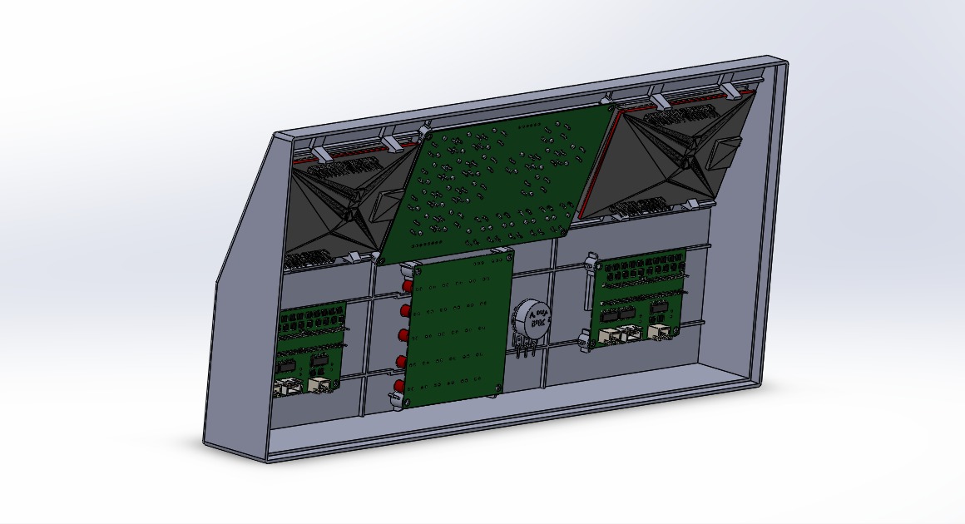
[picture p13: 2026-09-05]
images/cross_section_view.jpg

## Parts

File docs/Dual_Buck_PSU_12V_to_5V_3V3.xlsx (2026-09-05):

Line # | Comment | Description | Designator | Revision ID | Revision Status | Quantity | Manufacturer 1 | Manufacturer Part Number 1 | Manufacturer Lifecycle 1 | Supplier 1 | Supplier Part Number 1 | Supplier Unit Price 1 | Supplier Subtotal 1
 | MSAST219LB5106KTNA01E44L | MSAST219LB5106KTNA01 | C1 |  |  | 1
 | MSAST219LB5106KTNA01E44L | MSAST219LB5106KTNA01 | C2 |  |  | 1
 | 08053C104KAT2A | 08053C104KAT2A | C3 |  |  | 1
 | GRM21BR61A226ME44L | SMD capacitor X5R(EIA) with capacitance 22uF Tol.20%. Rated voltage 10Vdc 85C | C4 |  |  | 1
 | GRM21BR61A226ME44L | SMD capacitor X5R(EIA) with capacitance 22uF Tol.20%. Rated voltage 10Vdc 85C | C5 |  |  | 1
 | MSAST219LB5106KTNA01E44L | MSAST219LB5106KTNA01 | C6 |  |  | 1
 | MSAST219LB5106KTNA01E44L | MSAST219LB5106KTNA01 | C7 |  |  | 1
 | 08053C104KAT2A | 08053C104KAT2A | C8 |  |  | 1
 | GRM21BR61A226ME44L | SMD capacitor X5R(EIA) with capacitance 22uF Tol.20%. Rated voltage 10Vdc 85C | C9 |  |  | 1
 | GRM21BR61A226ME44L | SMD capacitor X5R(EIA) with capacitance 22uF Tol.20%. Rated voltage 10Vdc 85C | C10 |  |  | 1
 | 691137710002 | Terminal Block, 5MM Pitch, Horizontal, Pressure Clamp Glow Wire, Pcb, 2PINS, Gr | J1 |  |  | 1
 | B2B-XH-A(LF)(SN) | CONN HEADER VERT 2POS 2.5MM | J2 |  |  | 1
 | B2B-XH-A(LF)(SN) | CONN HEADER VERT 2POS 2.5MM | J3 |  |  | 1
 | B2B-XH-A(LF)(SN) | CONN HEADER VERT 2POS 2.5MM | J4 |  |  | 1
 | B2B-XH-A(LF)(SN) | CONN HEADER VERT 2POS 2.5MM | J5 |  |  | 1
 | B2B-XH-A(LF)(SN) | CONN HEADER VERT 2POS 2.5MM | J6 |  |  | 1
 | B2B-XH-A(LF)(SN) | CONN HEADER VERT 2POS 2.5MM | J7 |  |  | 1
 | B2B-XH-A(LF)(SN) | CONN HEADER VERT 2POS 2.5MM | J8 |  |  | 1
 | B2B-XH-A(LF)(SN) | CONN HEADER VERT 2POS 2.5MM | J9 |  |  | 1
 | SRN8040-3R3Y | FIXED IND 3.3UH 5.6A 21 MOHM SMD | L1 |  |  | 1
 | SDR0403-3R3ML | SDR0403 Series Power Inductor, 3.3 uF +/- 20 %, 0.058 Ohm, -40 to 125 degC, 2-Pin SMD, RoHS, Tape and Reel | L2 |  |  | 1
 | RC0805FR-0756K2L |  | R1 |  |  | 1
 | RC0805FR-0710KL | Chip Resistor, 10 KOhm, +/- 1%, 0.125 W, -55 to 155 degC, 0805 (2012 Metric), RoHS, Tape and Reel | R2 |  |  | 1
 | RC0805FR-0710KL | Chip Resistor, 10 KOhm, +/- 1%, 0.125 W, -55 to 155 degC, 0805 (2012 Metric), RoHS, Tape and Reel | R3 |  |  | 1
 | RC0805FR-0710KL | Chip Resistor, 10 KOhm, +/- 1%, 0.125 W, -55 to 155 degC, 0805 (2012 Metric), RoHS, Tape and Reel | R4 |  |  | 1
 | CRCW080533K2FKEA | RES Thick Film, 33.2kΩ, 1%, 0.125W, 100ppm/°C, 0805 | R5 |  |  | 1
 | RC0805FR-0710KL | Chip Resistor, 10 KOhm, +/- 1%, 0.125 W, -55 to 155 degC, 0805 (2012 Metric), RoHS, Tape and Reel | R6 |  |  | 1
 | TPS563200DDCR | IC REG BUCK ADJ 3A TSOT23-6 | U1 |  |  | 1
 | TPS561208DDCR | 4.5V to 17V Input, 1A Output, Synchronous Step-Down Converter 6-SOT-23-THIN -40 to 125 | U2 |  |  | 1

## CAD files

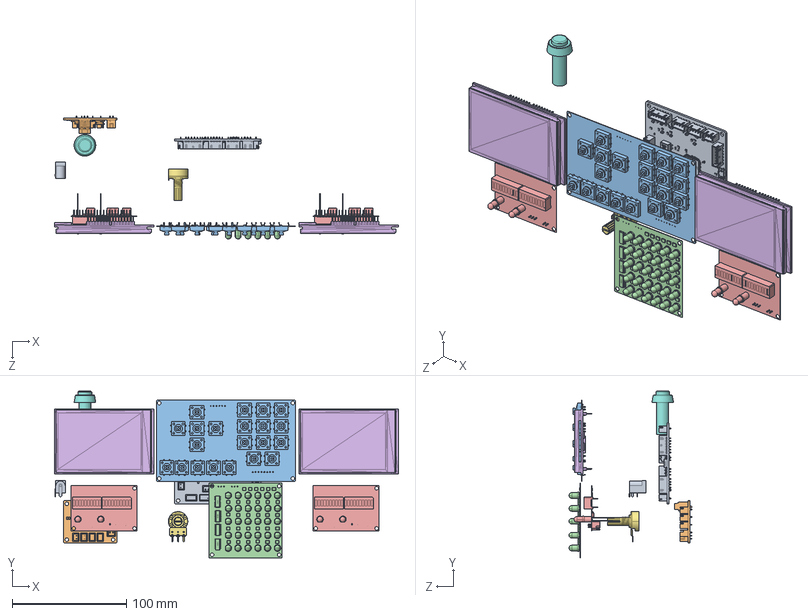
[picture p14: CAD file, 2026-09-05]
enclosure_designs/assembly/Assembly.SLDASM
300.9 x 145.9 x 107.6 mm
MCU
PSU
Keypad
LEDmatrix
LED_bars x 2
3,5 inch display x 2
potentiometer_B10K
power switch
DC_JACK

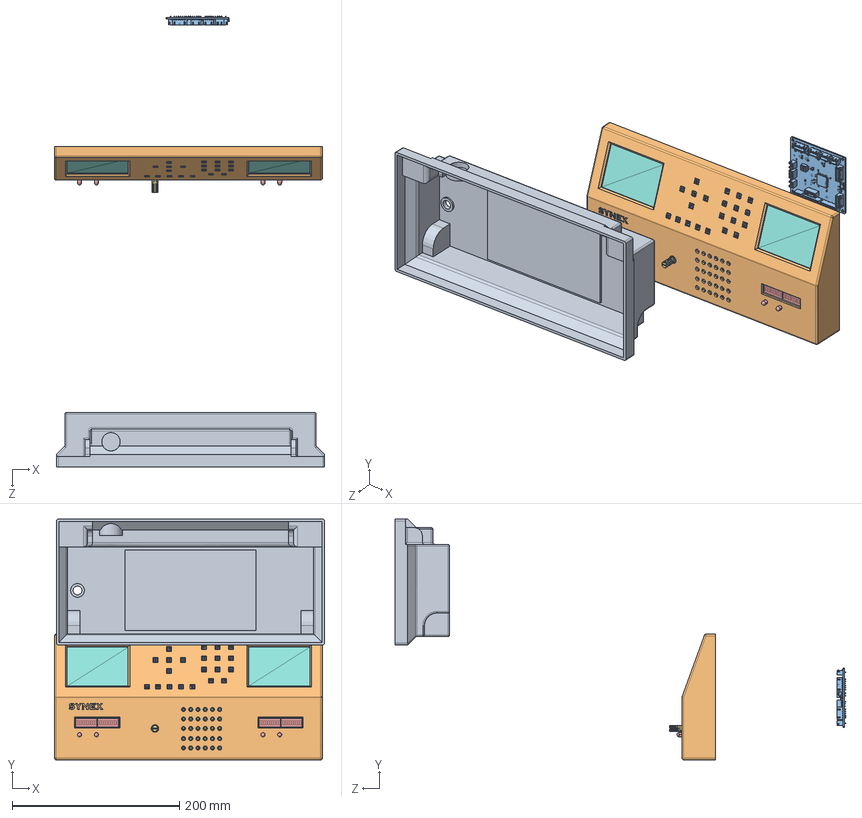
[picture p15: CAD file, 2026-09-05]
enclosure_designs/assembly/Assem2.SLDASM
322.5 x 287.5 x 538.3 mm
front_panel
LEDmatrix
LED_bars x 2
Keypad
potentiometer_B10K
3,5 inch display x 2

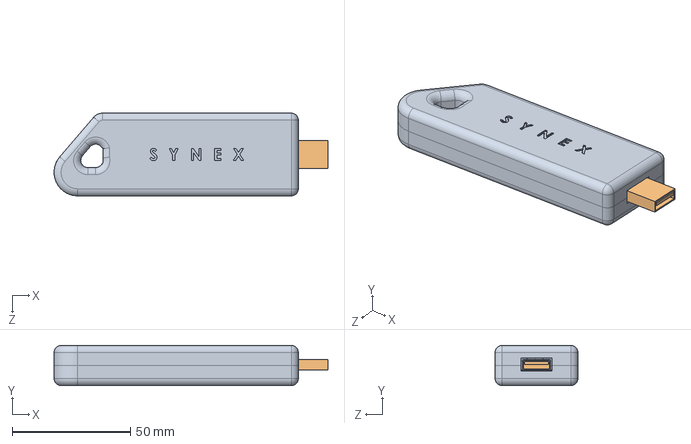
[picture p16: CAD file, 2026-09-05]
enclosure_designs/solidwork_assignment/Assembly.SLDASM
115.8 x 17.0 x 35.0 mm
Enclosure_Master
Parametric_PCB

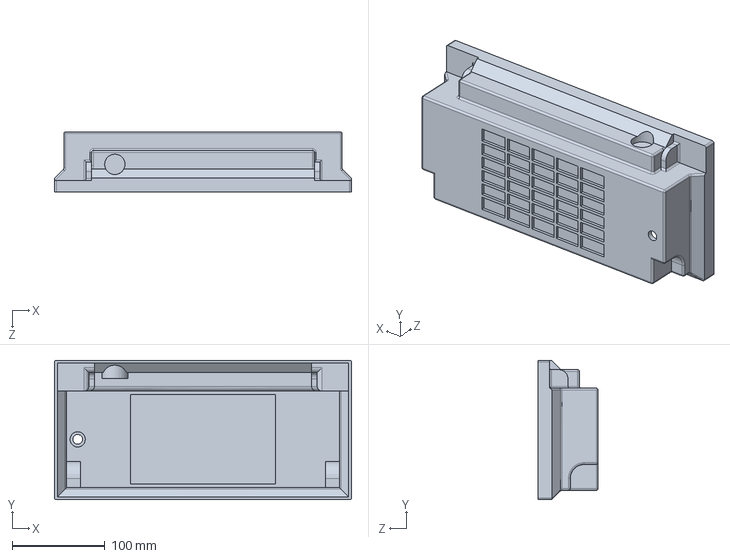
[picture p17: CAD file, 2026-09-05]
enclosure_designs/container/back_panel.SLDPRT
320.0 x 150.2 x 65.0 mm

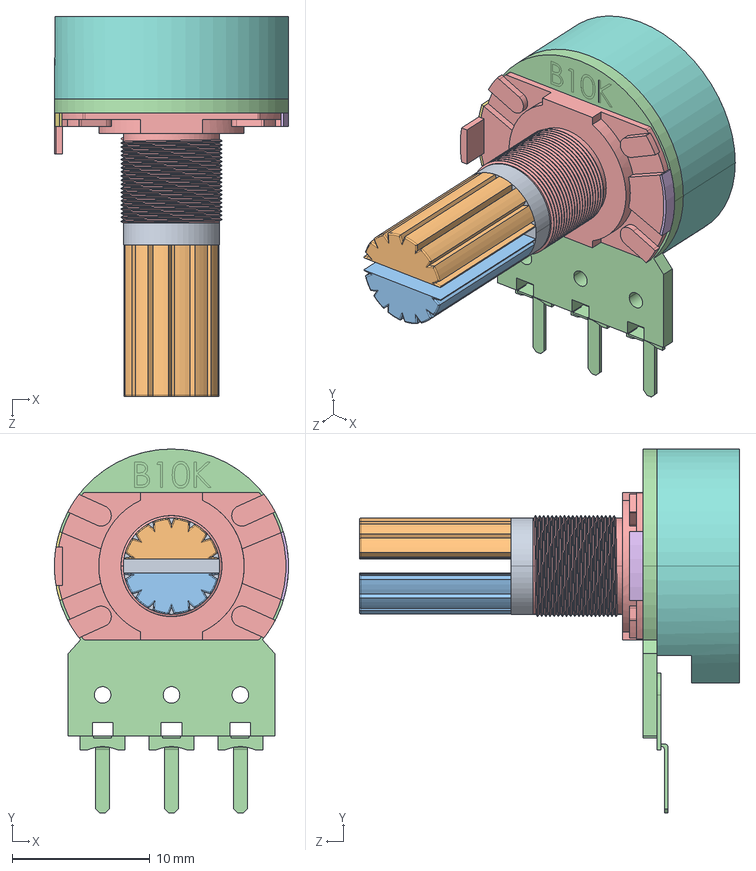
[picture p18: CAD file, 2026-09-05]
enclosure_designs/interfaces/potentiometer_B10K.STEP
17.0 x 26.4 x 27.6 mm

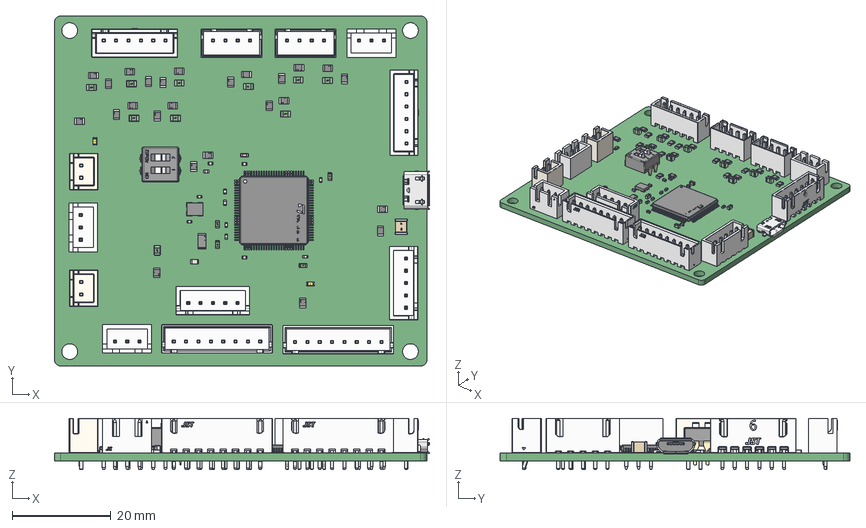
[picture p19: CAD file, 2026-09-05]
enclosure_designs/pcb_models/MCU.step
76.0 x 70.9 x 10.4 mm
pins x 25
logo x 25
side x 20
Samsung logo x 14
Extruded x 39
name x 2
Pins x 7
Leg x 2
STM Logo
B2B-XH-A x 2
JST Logo adjustable x 2
Pin1_Triangle x 6
JST x 6
Package x 2
Logo x 3
Molex Logo
Marking x 3
JST Logo x 3
Base x 2
Crystal x 2
Pads x 2
Lite-ON Logo x 2
Polarity Mark x 2

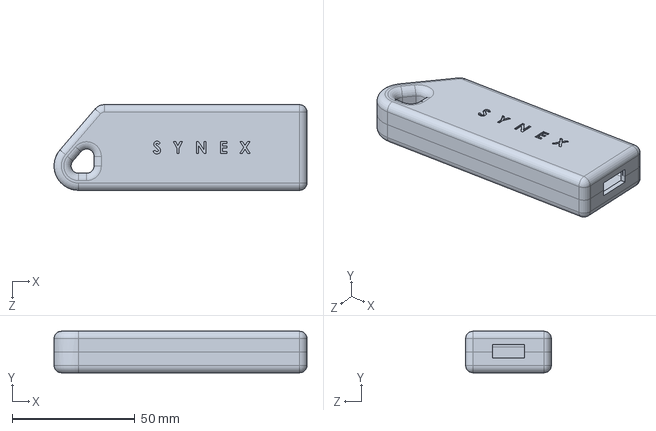
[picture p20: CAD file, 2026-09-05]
enclosure_designs/solidwork_assignment/Enclosure_Master.SLDPRT
103.3 x 17.0 x 35.0 mm

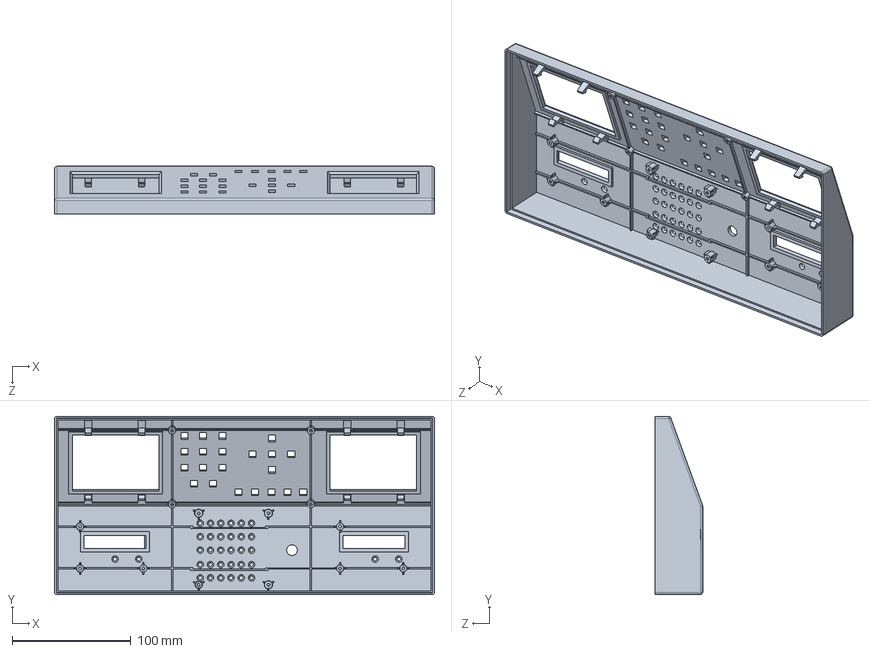
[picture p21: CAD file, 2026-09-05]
enclosure_designs/container/front_panel.SLDPRT
320.0 x 150.2 x 40.0 mm

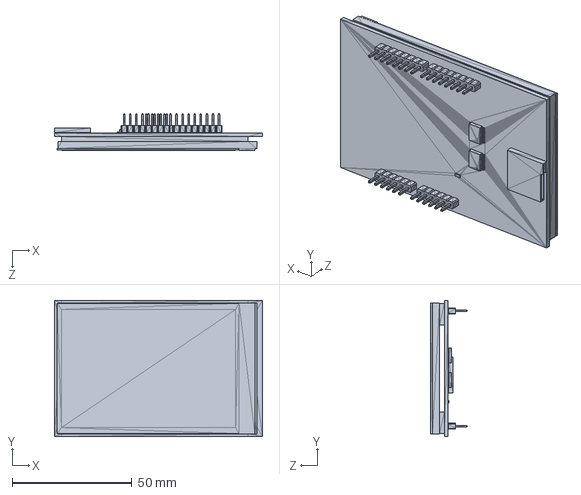
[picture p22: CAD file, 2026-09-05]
enclosure_designs/interfaces/3,5 inch display.SLDPRT
87.0 x 56.9 x 15.4 mm

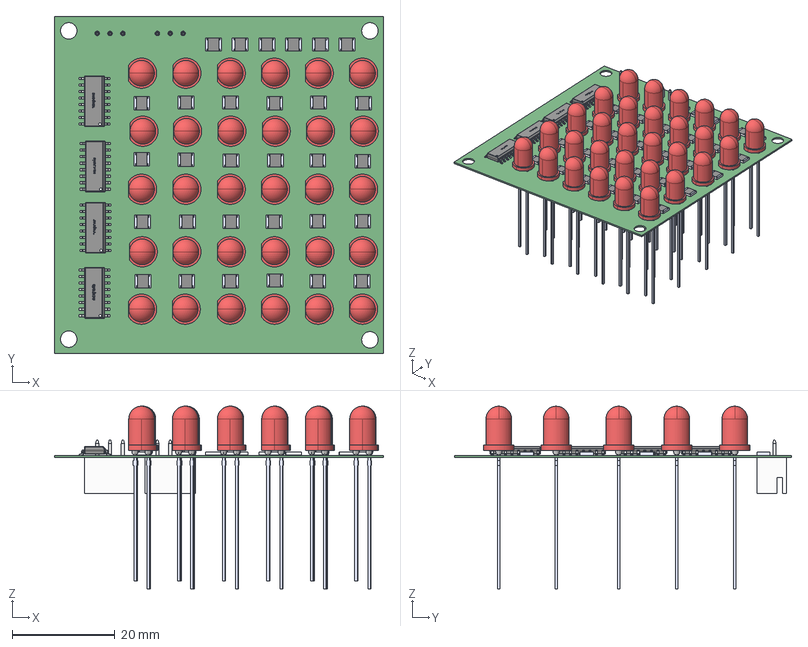
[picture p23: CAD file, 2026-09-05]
enclosure_designs/pcb_models/LEDmatrix.step
64.1 x 65.7 x 35.6 mm
Pins x 6
Marking x 6
JST Logo x 2
WP7113ID_WP7113ID x 30
Package x 4
Nexperia x 4

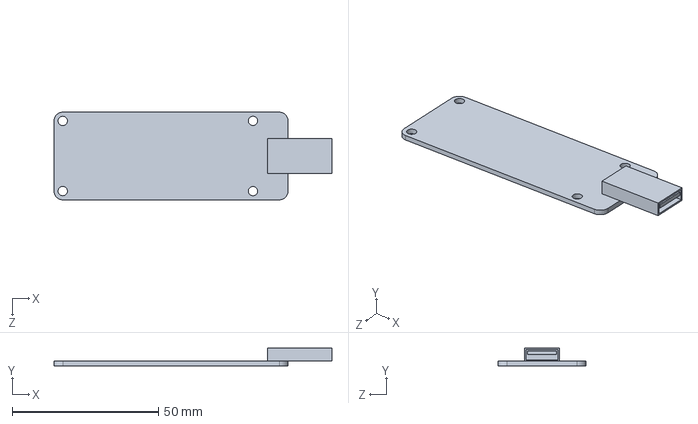
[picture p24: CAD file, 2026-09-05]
enclosure_designs/solidwork_assignment/Parametric_PCB.SLDPRT
95.0 x 6.10 x 30.0 mm

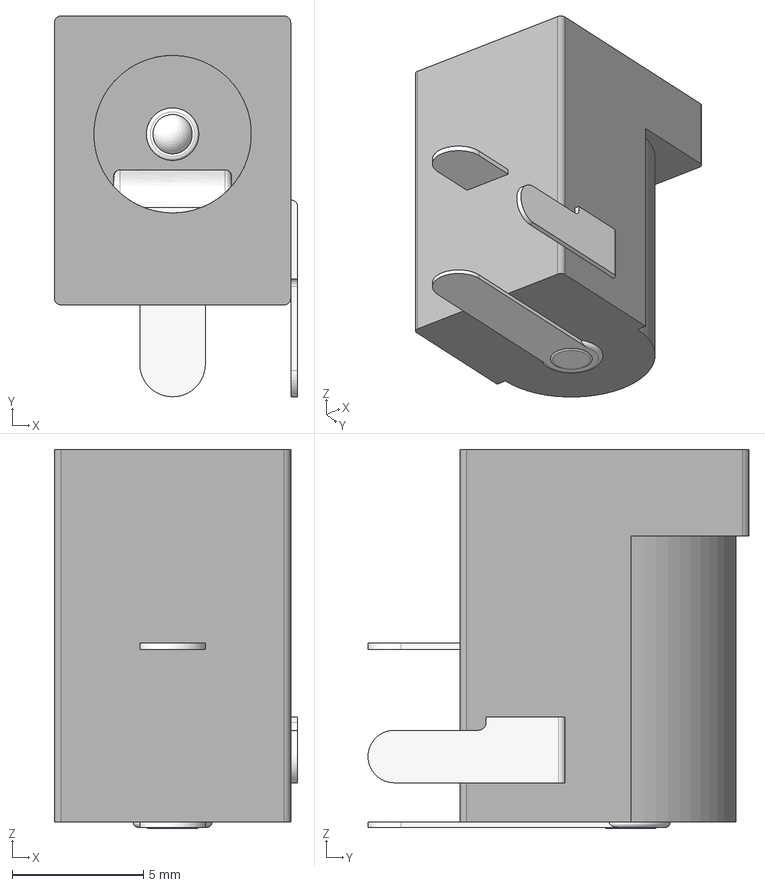
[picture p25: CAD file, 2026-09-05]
enclosure_designs/interfaces/DC_JACK.step
9.26 x 14.5 x 14.4 mm

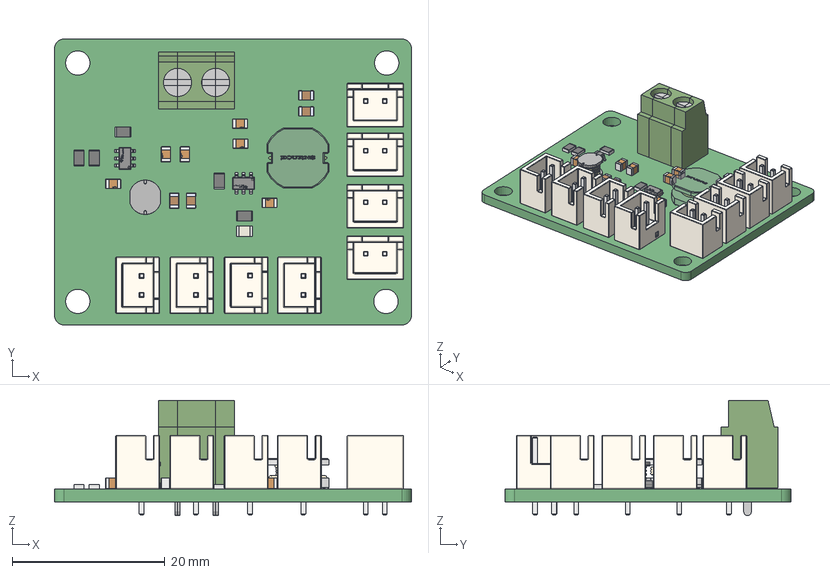
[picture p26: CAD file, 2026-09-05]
enclosure_designs/pcb_models/PSU.step
46.8 x 37.5 x 15.1 mm
B2B-XH-A x 8
JST Logo adjustable x 8
Extruded x 18
Mid_Body x 5
Mark x 5
pins x 2
part number x 2
Bourns
MRT12P5_SX
MRT12P5_CNT
MRT12P5_DX
side x 12
Murata x 6

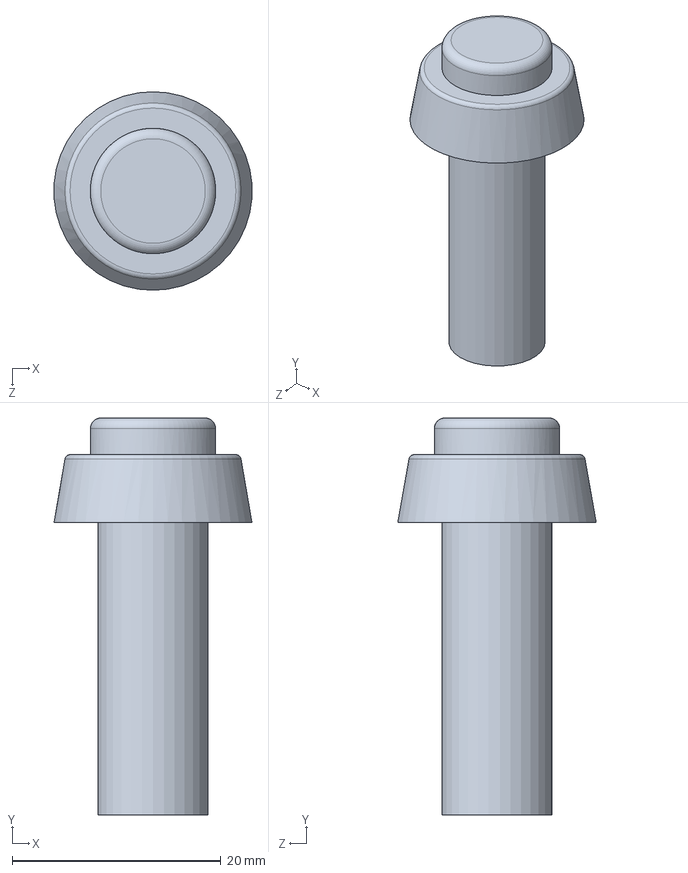
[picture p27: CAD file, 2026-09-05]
enclosure_designs/interfaces/power switch.SLDPRT
18.9 x 38.0 x 19.0 mm

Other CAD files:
enclosure_designs/pcb_models/LED_bars.step
enclosure_designs/solidwork_assignment/Bottom_Cover.SLDPRT
enclosure_designs/pcb_models/Keypad.step
enclosure_designs/solidwork_assignment/OLED Display 128x64.STEP
enclosure_designs/interfaces/3,5 inch display.stl
enclosure_designs/interfaces/DC_JACK.SLDPRT
enclosure_designs/interfaces/potentiometer_B10K.SLDPRT
enclosure_designs/pcb_models/Keypad.SLDPRT
enclosure_designs/pcb_models/LED_bars.SLDPRT
enclosure_designs/pcb_models/LEDmatrix.SLDPRT
enclosure_designs/pcb_models/PSU.SLDPRT
enclosure_designs/solidwork_assignment/OLED Display 128x64.SLDPRT
enclosure_designs/solidwork_assignment/Top_Cover.SLDPRT

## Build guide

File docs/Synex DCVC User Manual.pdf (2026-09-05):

# USER MANUAL

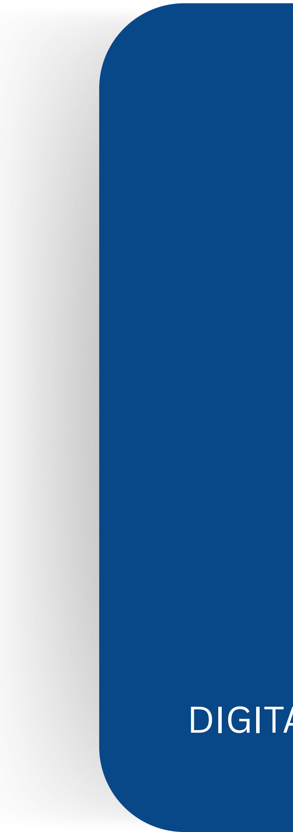
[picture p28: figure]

www.synex.com | DIGITAL COMMUNICATION VISUALIZATION CONSOLE

TEAM SYNEX

# ABOUT US

www.synex.com

Thank you for purchasing the Digital Communication Visualization Console (DCVC). This system is proudly engineered by Synex Engineering.

The DCVC is a standalone bench instrument. It is designed specifically to serve as an interactive desktop laboratory tool. The console translates abstract digital communication theories into clear visual layouts. It displays the entire pipeline, from message character inputs to real-time vector channel transmissions.

Users can easily manipulate data alphabets, runtime parameters, packet frames, and physical analog noise. This hands-on approach allows engineering students, training center operators, and electronics hobbyists to monitor complex bit manipulation in real time.

2
Team SyneX

# PACKAGE CONTENT

www.synex.com

Team SyneX

1× Synex Digital Communication Visualization Console (DCVC) Unit

1× High-Stability AC-to-DC 12V Power Adapter

1× Official Warranty Card

1× DCVC Hardware User Manual

3

# SAFETY

# PRECAUTIONS

www.synex.com

Team SyneX

Please read these guidelines carefully before operating the console. Following these instructions will protect both the user and the device.

Only use the included 12V DC power adapter. Using third-party chargers may deliver incorrect voltage and permanently damage the internal circuit boards.

Do not block the cooling vents on the casing. The internal power regulators require continuous airflow to manage heat efficiently during long laboratory sessions.

Keep water, coffee, and other liquids away from the console. Spills can cause short circuits on the exposed keypad and internal PCB tracks.

Always place the device on a stable, flat desktop surface. Do not drop the console.

Do not attempt to open the enclosure while the device is plugged
in. | 4

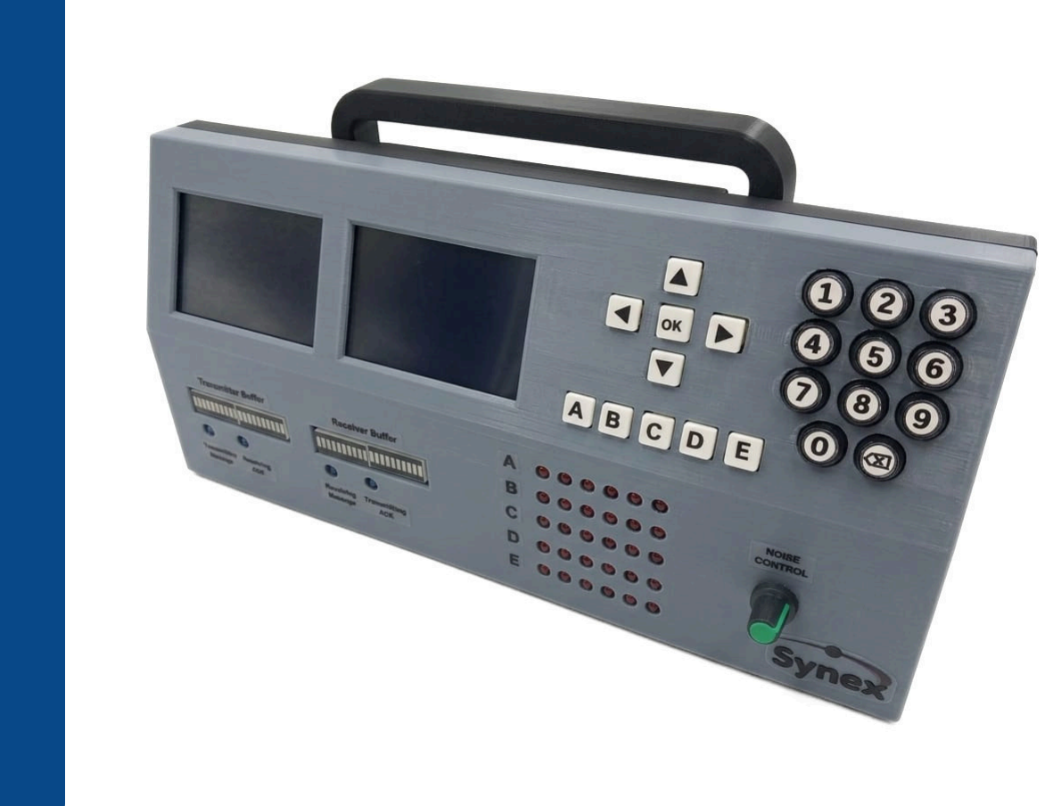
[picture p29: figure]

# DEVICE OVERVIEW

www.synex.com

Team SyneX

5

# FEATURES

www.synex.com

Team SyneX

6

Real-Time Source Coding: Supports Fixed-length, Huffman, and Shannon-Fano compression algorithms.

Adjustable Data Framing: Splits data streams into customizable 4-bit, 6-bit, or 8-bit packets.

Built-in Error Protection: Applies Parity, CRC, and Hamming block codes to secure data frames.

Multiple Modulations: Generates real-time waveforms for ASK, BPSK, QPSK, and 16-QAM.

Dual Display System: Utilizes two 3.5" screens to show control menus and signal graphs simultaneously.

Live LED Tracking: Features a 24-LED array to visually monitor binary data streams as they process.

Interactive Channel Noise: Includes a physical analog dial to inject interference and observe real-time signal corruption.

# QUICK START GUIDE

www.synex.com

Team SyneX

Follow these simple steps to safely power on your Digital Communication Visualization Console (DCVC) for the first time.

1.Position the Console:Ensure a stable setup.Place the DCVC unit on a clean, flat laboratory desk. Ensure the cooling vents on the casing are not blocked.

2.Connect the Power:Use only the provided 12V adapter.Plug the included power adapter into a standard wall outlet. Then, insert the connector into the DC power port on the back of the console.

3.Turn on the Device:Press the power switch located on the back panel next to the power port.

4.Observe the Boot Sequence:Hardware initialization.The 24 LED indicators will flash briefly as the system runs a hardware check. Both 3.5" TFT screens will light up and display the Synex Engineering logo.

5.Ready for Input:After a few seconds, the left screen will load the Main Menu. The right screen will show a standby grid. The device is now ready, and you can use the keypad to start your first simulation.

7

# SOURCE CODING

www.synex.com

Team SyneX

8

The console uses a specific alphabet set for data input: S = {A, B, C, D, E}. Follow these steps to compress your data.

1.Open the Menu:Navigate to the Source Compiling Menu on the left screen (Screen 1).

2.Choose an Algorithm:Fixed-Length, Huffman, or Shannon-Fano.Select your desired compression algorithm using the keypad.

3.Set Probabilities:Required for Huffman and Shannon-Fano.If prompted, type in the probability for each character. Ensure all the probabilities add up to exactly 1.0.

4.Type Your Message:Use the keys [A] through [E] to type your custom message sequence.

5.Process the Data:Press the [#] key. The system will process your message, and the generated binary compression tree will appear instantly on Screen 1.

# FRAMING METHODS

www.synex.com

Team SyneX

9

After compressing your data, the system allows you to split the data stream into distinct packets. This feature operates in real time.
Select one of the following packet sizes from the menu to set your frame boundaries.

4-bit Packets: Best for observing short-block transmissions and basic data tracking.

6-bit Packets: An intermediate layout for testing medium-sized data frames.

8-bit Packets: The traditional, full-byte formatting configuration.

# CHANNEL CODING

www.synex.com

Team SyneX

10

To protect your data packets from errors, you must add mathematical protection bits.

1.Open Channel Coding:Navigate to the Channel Coding Sub-Menu on Screen 1.

2.Select a Protection Mode:Parity or CRC.Choose either standard Parity Validation (Even/Odd) or a Cyclic Redundancy Check (CRC-3 or CRC-4).

3.Enter the Polynomial:For CRC modes only.If you selected CRC, use the keypad to type your generator polynomial code. For example, typing '1011' will set up a 4-bit CRC generator.

4.Apply the Protection:Press the [#] key. The system will automatically calculate the remainder codes and attach them to your packets.

# HARDWARE

# SPECIFICATIONS

www.synex.com

Team SyneX

11

The following details the core electrical and mechanical specifications of the DCVC unit.

Core Controller Engine: STM32 ARM Cortex-M Series (32-bit Architecture)

Input Operating Voltage: 12V DC Sourced Line (via the enclosed adapter)

Display Panel Hardware: Dual 3.5” SPI TFT Screens (320 × 480 resolution)

Bit Tracking Diagnostic: 24-Channel LED Matrix driven via three cascaded 74HC595 ICs

# MAINTENANCE &

## TROUBLESHOOTING

www.synex.com

Team SyneX

12

Follow these guidelines to keep your console operating smoothly and to resolve common issues.

Cleaning the Enclosure: Wipe the 3D-printed chassis with a soft, dry microfiber cloth. Do not use chemical solvents or abrasive sprays, especially near the glass screens.

Powering Down: Unplug the 12V power adapter from the wall outlet if the console will not be used for an extended period.

# WARRANTY & SUPPORT

www.synex.com

Team SyneX

13

Legal Exclusions: Synex Engineering is not responsible for hardware damage caused by incorrect power supplies, liquid exposure, or unauthorized modifications. Furthermore, we are not liable for academic laboratory failures or grading issues related to the use of this device.

Limited Warranty Information: The DCVC unit comes with a 2-year limited warranty from the purchase date. This warranty covers internal manufacturing defects and component failures that occur under normal laboratory use.
The warranty will be immediately voided if:
The 3D-printed enclosure is opened or modified.
The device suffers physical impact damage (e.g., dropping). A third-party or incorrect power adapter is used.

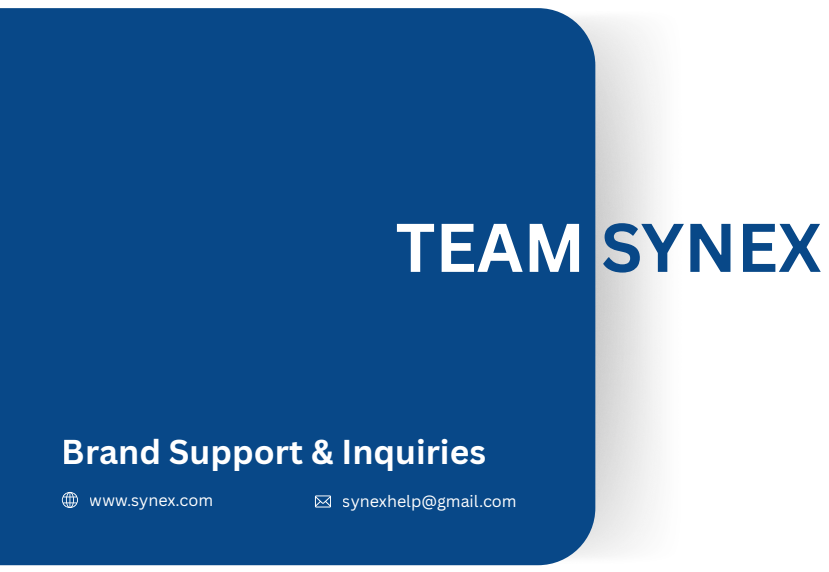
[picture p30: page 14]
TEAM SYNEX; www.synex.com; synexhelp@gmail.com

Brand Support & Inquiries

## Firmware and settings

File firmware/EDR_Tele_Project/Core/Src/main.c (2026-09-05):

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
/* Includes ------------------------------------------------------------------*/
#include "main.h"
#include <string.h>
#include <stdio.h>

void SystemClock_Config(void);
static void MPU_Config(void);
static void MX_GPIO_Init(void);

/* USER CODE BEGIN PFP */
/**
  * Generic parallel-bus pin description, so the same driver code can drive
  * either physical display just by passing a different LCD_Pins instance —
  * avoids duplicating every drawing function for Display 2.
  */
typedef struct {
  GPIO_TypeDef* rst_port; uint16_t rst_pin;
  GPIO_TypeDef* cs_port;  uint16_t cs_pin;
  GPIO_TypeDef* rs_port;  uint16_t rs_pin;  // RS/DC
  GPIO_TypeDef* wr_port;  uint16_t wr_pin;
  GPIO_TypeDef* rd_port;  uint16_t rd_pin;
  GPIO_TypeDef* data_port; // 8-bit data bus on bits 8-15 of this port (D0-D7)
} LCD_Pins;

static const LCD_Pins LCD1_PINS = {
  .rst_port = GPIOE, .rst_pin = GPIO_PIN_7,
  .cs_port  = GPIOB, .cs_pin  = GPIO_PIN_2,
  .rs_port  = GPIOB, .rs_pin  = GPIO_PIN_1,
  .wr_port  = GPIOB, .wr_pin  = GPIO_PIN_0,
  .rd_port  = GPIOC, .rd_pin  = GPIO_PIN_5,
  .data_port = GPIOE
};

static const LCD_Pins LCD2_PINS = {
  .rst_port = GPIOC, .rst_pin = GPIO_PIN_6,
  .cs_port  = GPIOC, .cs_pin  = GPIO_PIN_7,
  .rs_port  = GPIOC, .rs_pin  = GPIO_PIN_8,
  .wr_port  = GPIOC, .wr_pin  = GPIO_PIN_9,
  .rd_port  = GPIOA, .rd_pin  = GPIO_PIN_8,
  .data_port = GPIOD
};

static inline void WR_STROBE(const LCD_Pins* lcd);
void write8(const LCD_Pins* lcd, uint8_t d);
void writeCommand(const LCD_Pins* lcd, uint8_t c);
void writeData(const LCD_Pins* lcd, uint8_t d);
void lcdReset(const LCD_Pins* lcd);
void lcdInit(const LCD_Pins* lcd);
void setAddr(const LCD_Pins* lcd, uint16_t x1, uint16_t y1, uint16_t x2, uint16_t y2);
void fillScreen(const LCD_Pins* lcd, uint16_t color);
void drawRectangle(const LCD_Pins* lcd, uint16_t x, uint16_t y, uint16_t w, uint16_t h, uint16_t color);
void drawChar(const LCD_Pins* lcd, char ch, uint16_t x, uint16_t y, uint8_t scale, uint16_t color, uint16_t bg);
void printString(const LCD_Pins* lcd, const char* str, uint16_t x, uint16_t y, uint8_t scale, uint16_t color, uint16_t bg);
void checkNavKeys(void);
void scanMatrixKeypad(void);
void handleMatrixKeyPress(uint8_t row, uint8_t col);
void Process_UI_Screen_Updates(void);
void Append_Char(char c);
void Backspace_Char(void);
void Confirm_Message(void);
void Move_Selection(int8_t delta);
void Confirm_Coding_Selection(void);
void Prob_Digit(uint8_t digit);
void Prob_Backspace(void);
void Confirm_Prob_Entry(void);
/* USER CODE END PFP */

typedef enum {
  STATE_ENTER_MSG,
  STATE_SELECT_CODING,
  STATE_ENTER_PROBS,    // Huffman/Shannon Fano: enter A-E probabilities
  STATE_FIXED_RESULT,   // Fixed Length: show A-E code table
  STATE_CONFIRMED       // Final confirmation screen
} AppState;

static AppState app_state = STATE_ENTER_MSG;
static AppState last_rendered_state = (AppState)-1; // forces first-time full draw
static int8_t coding_selection = 0; // 0=Fixed, 1=Huffman, 2=Shannon Fano
static int8_t last_rendered_selection = -1;

// Probability entry state
static uint8_t  prob_cursor = 0;           // which character (0=A .. 4=E) is active
static uint16_t prob_values[5] = {0,0,0,0,0}; // confirmed % for each character
static uint16_t prob_current = 0;          // digits being typed for the active char
static uint8_t  prob_has_input = 0;        // whether user typed anything yet
static uint8_t  last_prob_cursor = 0xFF;   // track cursor for partial redraws

// ---- CODING RESULT STATE ----
// Binary tree node (max 9 nodes for 5 symbols: 2*5-1)
#define MAX_NODES 9
typedef struct {
  int8_t  left;       // index of left child (-1 = none)
  int8_t  right;      // index of right child (-1 = none)
  int8_t  parent;     // index of parent (-1 = root)
  uint8_t is_leaf;    // 1 if this node is a symbol
  uint8_t symbol;     // 0-4 (A-E) if is_leaf
  uint16_t prob;      // combined probability (sum of children)
  uint16_t node_x;    // pixel x for drawing
  uint16_t node_y;    // pixel y for drawing
} TreeNode;

static TreeNode tree_nodes[MAX_NODES];
static uint8_t  tree_node_count = 0;
static int8_t   tree_root = -1;

// Generated codes for each symbol (A=0..E=4)
static char     sym_codes[5][8];   // e.g. "110\0"
static uint8_t  sym_code_len[5];

// Currently selected symbol on the result screen (for path highlighting)
static int8_t   result_cursor = 0;
static int8_t   last_result_cursor = -1;

void Build_Huffman_Tree(void);
void Build_Shannon_Fano(int8_t* indices, uint8_t count, uint8_t depth, uint8_t node_idx);
int8_t  SF_Make_Node(uint8_t is_leaf, uint8_t symbol, uint16_t prob);
void Layout_Tree(int8_t node, uint16_t x, uint16_t y_min, uint16_t y_max);
void Draw_Tree_On_D2(int8_t highlight_symbol);
void Draw_Result_Table(void);
void Extract_Codes(int8_t node, char* prefix, uint8_t depth);

static const char* coding_options[3] = {
  "Fixed Length Coding",
  "Huffman Coding",
  "Shannon Fano Coding"
};

/* Short descriptions shown on Display 2 while a coding method is selected,
   updating live as the user moves Up/Down before pressing OK. */
static const char* coding_descriptions[3] = {
  "FIXED LENGTH CODING ASSIGNS EVERY SYMBOL THE SAME NUMBER OF BITS, REGARDLESS OF HOW OFTEN IT APPEARS.",
  "HUFFMAN CODING BUILDS A BINARY TREE FROM SYMBOL FREQUENCIES, GIVING SHORTER CODES TO MORE FREQUENT SYMBOLS.",
  "SHANNON FANO CODING SPLITS SYMBOLS INTO TWO GROUPS OF NEARLY EQUAL PROBABILITY, REPEATEDLY, TO BUILD VARIABLE LENGTH CODES."
};

/* Industry Standard 5x7 Font Table for Alpha-Numerics */
const uint8_t standard_font5x7[][5] = {
  {0x3E, 0x51, 0x49, 0x45, 0x3E}, // 0
  {0x00, 0x42, 0x7F, 0x40, 0x00}, // 1
  {0x42, 0x61, 0x51, 0x49, 0x46}, // 2
  {0x21, 0x41, 0x45, 0x4B, 0x31}, // 3
  {0x18, 0x14, 0x12, 0x7F, 0x10}, // 4
  {0x27, 0x45, 0x45, 0x45, 0x39}, // 5
  {0x3C, 0x4A, 0x49, 0x49, 0x30}, // 6
  {0x01, 0x71, 0x09, 0x05, 0x03}, // 7
  {0x36, 0x49, 0x49, 0x49, 0x36}, // 8
  {0x06, 0x49, 0x49, 0x29, 0x1E}, // 9
  {0x7E, 0x11, 0x11, 0x11, 0x7E}, // A
  {0x7F, 0x49, 0x49, 0x49, 0x36}, // B
  {0x3E, 0x41, 0x41, 0x41, 0x22}, // C
  {0x7F, 0x41, 0x41, 0x22, 0x1C}, // D
  {0x7F, 0x49, 0x49, 0x49, 0x41}, // E
  {0x7F, 0x09, 0x09, 0x09, 0x01}, // F
  {0x3E, 0x41, 0x49, 0x49, 0x7A}, // G
  {0x7F, 0x08, 0x08, 0x08, 0x7F}, // H
  {0x00, 0x41, 0x7F, 0x41, 0x00}, // I
  {0x20, 0x40, 0x41, 0x3F, 0x01}, // J
  {0x7F, 0x08, 0x14, 0x22, 0x41}, // K
  {0x7F, 0x40, 0x40, 0x40, 0x40}, // L
  {0x7F, 0x02, 0x0C, 0x02, 0x7F}, // M
  {0x7F, 0x04, 0x08, 0x10, 0x7F}, // N
  {0x3E, 0x41, 0x41, 0x41, 0x3E}, // O
  {0x7F, 0x09, 0x09, 0x09, 0x06}, // P
  {0x3E, 0x41, 0x51, 0x21, 0x5E}, // Q
  {0x7F, 0x09, 0x19, 0x29, 0x46}, // R
  {0x46, 0x49, 0x49, 0x49, 0x31}, // S
  {0x01, 0x01, 0x7F, 0x01, 0x01}, // T
  {0x3F, 0x40, 0x40, 0x40, 0x3F}, // U
  {0x1F, 0x20, 0x40, 0x20, 0x1F}, // V
  {0x3F, 0x40, 0x38, 0x40, 0x3F}, // W
  {0x63, 0x14, 0x08, 0x14, 0x63}, // X
  {0x07, 0x08, 0x70, 0x08, 0x07}, // Y
  {0x61, 0x51, 0x49, 0x45, 0x43}, // Z
  {0x00, 0x00, 0x00, 0x00, 0x00}, // Space
  {0x40, 0x40, 0x40, 0x40, 0x40}, // _ (Cursor)
  {0x00, 0x36, 0x36, 0x00, 0x00}, // : (idx 38)
  {0x00, 0x1C, 0x22, 0x41, 0x00}, // ( (idx 39)
  {0x00, 0x41, 0x22, 0x1C, 0x00}, // ) (idx 40)
  {0x20, 0x10, 0x08, 0x04, 0x02}, // / (idx 41)
  {0x00, 0x60, 0x60, 0x00, 0x00}, // . (idx 42)
  {0x41, 0x22, 0x14, 0x08, 0x00}, // > (idx 43)
  {0x23, 0x13, 0x08, 0x64, 0x62}  // % (idx 44)
};

/* User-confirmed working layout: */
const char matrix_mapping[4][4] = {
  {'E', 'D', 'C', 'B'},
  {'A', '<', '0', '9'},
  {'8', '7', '6', '5'},
  {'4', '3', '2', '1'}
};

/* --- SYSTEM STRING VARIABLES (accumulating message) --- */
char message_buffer[64] = "";
int message_len = 0;

const uint16_t prompt_x = 10;
const uint16_t prompt_y = 15;
const uint8_t  prompt_scale = 2;

const uint16_t msg_x = 10;
const uint16_t msg_y = 60;
const uint8_t  msg_scale = 3;

int main(void)
{
  MPU_Config();
  HAL_Init();
  SystemClock_Config();
  MX_GPIO_Init();

  /* USER CODE BEGIN 2 */
  HAL_GPIO_WritePin(GPIOB, GPIO_PIN_2, GPIO_PIN_SET);
  HAL_GPIO_WritePin(GPIOB, GPIO_PIN_0, GPIO_PIN_SET);
  HAL_GPIO_WritePin(GPIOC, GPIO_PIN_5, GPIO_PIN_SET);

  lcdInit(&LCD1_PINS);
  lcdInit(&LCD2_PINS);

  message_buffer[0] = '\0';
  message_len = 0;

  Process_UI_Screen_Updates();
  /* USER CODE END 2 */

  while (1)
  {
    /* USER CODE BEGIN 3 */
    checkNavKeys();
    scanMatrixKeypad();
    HAL_Delay(10);
    /* USER CODE END 3 */
  }
}

/**
  * @brief Appends a character to the message buffer and refreshes the screen.
  */
void Append_Char(char c)
{
  if (app_state != STATE_ENTER_MSG) return;
  if (message_len < 63) {
    message_buffer[message_len++] = c;
    message_buffer[message_len] = '\0';
    Process_UI_Screen_Updates();
  }
}

/**
  * @brief Removes the last character from the message buffer and refreshes the screen.
  */
void Backspace_Char(void)
{
  if (app_state != STATE_ENTER_MSG) return;
  if (message_len > 0) {
    message_buffer[--message_len] = '\0';
    Process_UI_Screen_Updates();
  }
}

/**
  * @brief OK pressed while entering the message: move to coding-method
  *        selection screen. Ignored if the message is empty.
  */
void Confirm_Message(void)
{
  if (app_state != STATE_ENTER_MSG) return;
  if (message_len == 0) return; // nothing typed yet, ignore OK

  app_state = STATE_SELECT_CODING;
  coding_selection = 0;
  Process_UI_Screen_Updates();
}

/**
  * @brief Up/Down on the coding-selection screen moves the highlighted option.
  */
void Move_Selection(int8_t delta)
{
  if (app_state != STATE_SELECT_CODING) return;

  int8_t next = coding_selection + delta;
  if (next < 0) next = 0;
  if (next > 2) next = 2;

  if (next != coding_selection) {
    coding_selection = next;
    Process_UI_Screen_Updates();
  }
}

/**
  * @brief OK pressed on the coding-selection screen.
  *        Fixed Length -> show code table.
  *        Huffman / Shannon Fano -> enter probability screen.
  */
void Confirm_Coding_Selection(void)
{
  if (app_state != STATE_SELECT_CODING) return;

  if (coding_selection == 0) {
    // Fixed Length Coding — skip probabilities, show code table
    app_state = STATE_FIXED_RESULT;
  } else {
    // Huffman (1) or Shannon Fano (2) — need probabilities
    prob_cursor = 0;
    prob_current = 0;
    prob_has_input = 0;
    last_prob_cursor = 0xFF;
    for (uint8_t i = 0; i < 5; i++) prob_values[i] = 0;
    app_state = STATE_ENTER_PROBS;
  }
  Process_UI_Screen_Updates();
}

/**
  * @brief A digit key was pressed during probability entry.
  *        Builds the current value up to 3 digits (max 100).
  */
void Prob_Digit(uint8_t digit)
{
  if (app_state != STATE_ENTER_PROBS) return;
  uint16_t next = prob_current * 10 + digit;
  if (next > 100) return;
  prob_current = next;
  prob_has_input = 1;
  Process_UI_Screen_Updates();
}

/**
  * @brief Backspace during probability entry: drops the last typed digit.
  */
void Prob_Backspace(void)
{
  if (app_state != STATE_ENTER_PROBS) return;
  prob_current = prob_current / 10;
  Process_UI_Screen_Updates();
}

/**
  * @brief OK pressed during probability entry: confirms the current
  *        character's value and advances the cursor. After E, validates
  *        that all five values sum to 100.
  */
void Confirm_Prob_Entry(void)
{
  if (app_state != STATE_ENTER_PROBS) return;

  prob_values[prob_cursor] = prob_current;
  prob_current = 0;
  prob_has_input = 0;

  if (prob_cursor < 4) {
    prob_cursor++;
    last_prob_cursor = 0xFF;
    Process_UI_Screen_Updates();
  } else {
    uint16_t total = 0;
    for (uint8_t i = 0; i < 5; i++) total += prob_values[i];

    if (total != 100) {
      // Invalid: reset cursor to A, redraw entry screen, show error on D2
      prob_cursor = 0;
      last_prob_cursor = 0xFF;
      last_rendered_state = (AppState)-1; // force full D1 redraw
      Process_UI_Screen_Updates();
      drawRectangle(&LCD2_PINS, 0, 80, 480, 200, 0x0000);
      printString(&LCD2_PINS, "INVALID PROBABILITY", 10, 90, 2, 0xF800, 0x0000);
      printString(&LCD2_PINS, "VALUES. TOTAL MUST", 10, 120, 2, 0xF800, 0x0000);
      printString(&LCD2_PINS, "EQUAL 100%.", 10, 150, 2, 0xF800, 0x0000);
      printString(&LCD2_PINS, "RE-ENTER FROM A.", 10, 180, 2, 0xF800, 0x0000);
    } else {
      result_cursor = 0;
      last_result_cursor = -1;
      app_state = STATE_CONFIRMED;
      Process_UI_Screen_Updates();
    }
  }
}

/**
  * @brief Translates a matrix key press into a buffer edit. Only active
  *        while typing the message: A-E append a letter, '<' backspaces.
  *        Digits and '0' (space) are ignored per spec — only A-E allowed.
  *        Once in the coding-selection state, matrix keys are ignored;
  *        selection is done with nav buttons only.
  */
void handleMatrixKeyPress(uint8_t row, uint8_t col)
{
  char key = matrix_mapping[row][col];

  if (app_state == STATE_ENTER_MSG) {
    if (key == '<') {
      Backspace_Char();
    } else if (key >= 'A' && key <= 'E') {
      Append_Char(key);
    }
    // digits ignored in message entry

  } else if (app_state == STATE_ENTER_PROBS) {
    if (key >= '1' && key <= '9') {
      Prob_Digit(key - '0');
    } else if (key == '0') {
      Prob_Digit(0);
    } else if (key == '<') {
      Prob_Backspace();
    }
    // A-E ignored in probability entry
  }
}

void checkNavKeys(void)
{
  static uint8_t prev_B5 = 1, prev_B6 = 1, prev_B7 = 1, prev_B8 = 1, prev_B9 = 1;

  uint8_t curr_B5 = HAL_GPIO_ReadPin(GPIOB, GPIO_PIN_5); // OK/Enter
  uint8_t curr_B6 = HAL_GPIO_ReadPin(GPIOB, GPIO_PIN_6); // Right (unused)
  uint8_t curr_B7 = HAL_GPIO_ReadPin(GPIOB, GPIO_PIN_7); // Left (unused)
  uint8_t curr_B8 = HAL_GPIO_ReadPin(GPIOB, GPIO_PIN_8); // Down
  uint8_t curr_B9 = HAL_GPIO_ReadPin(GPIOB, GPIO_PIN_9); // Up

  if (prev_B9 == 1 && curr_B9 == 0) { // Up
    if (app_state == STATE_SELECT_CODING) {
      Move_Selection(-1);
    } else if (app_state == STATE_CONFIRMED) {
      if (result_cursor > 0) { result_cursor--; Process_UI_Screen_Updates(); }
    }
  }
  if (prev_B8 == 1 && curr_B8 == 0) { // Down
    if (app_state == STATE_SELECT_CODING) {
      Move_Selection(+1);
    } else if (app_state == STATE_CONFIRMED) {
      if (result_cursor < 4) { result_cursor++; Process_UI_Screen_Updates(); }
    }
  }

  if (prev_B5 == 1 && curr_B5 == 0) {
    if (app_state == STATE_ENTER_MSG) {
      Confirm_Message();
    } else if (app_state == STATE_SELECT_CODING) {
      Confirm_Coding_Selection();
    } else if (app_state == STATE_ENTER_PROBS) {
      Confirm_Prob_Entry();
    }
  }

  prev_B5 = curr_B5; prev_B6 = curr_B6; prev_B7 = curr_B7; prev_B8 = curr_B8; prev_B9 = curr_B9;
}

/**
  * @brief Matrix Keypad Scanner — proven active-high row / no-pull column
  *        logic, confirmed working on this hardware. Unchanged from the
  *        version that correctly registered key changes.
  */
void scanMatrixKeypad(void)
{
    // All rows LOW
    HAL_GPIO_WritePin(GPIOD,
        GPIO_PIN_4 | GPIO_PIN_5 | GPIO_PIN_6 | GPIO_PIN_7,
        GPIO_PIN_RESET);

    for(int r = 0; r < 4; r++)
    {
        // Activate one row
        HAL_GPIO_WritePin(GPIOD, GPIO_PIN_4 << r, GPIO_PIN_SET);

        HAL_Delay(1);

        uint8_t d0 = HAL_GPIO_ReadPin(GPIOD, GPIO_PIN_0);
        uint8_t d1 = HAL_GPIO_ReadPin(GPIOD, GPIO_PIN_1);
        uint8_t d2 = HAL_GPIO_ReadPin(GPIOD, GPIO_PIN_2);
        uint8_t d3 = HAL_GPIO_ReadPin(GPIOD, GPIO_PIN_3);

        if(d0)
        {
            handleMatrixKeyPress(r,0);
            while(HAL_GPIO_ReadPin(GPIOD,GPIO_PIN_0));
        }

        if(d1)
        {
            handleMatrixKeyPress(r,1);
            while(HAL_GPIO_ReadPin(GPIOD,GPIO_PIN_1));
        }

        if(d2)
        {
            handleMatrixKeyPress(r,2);
            while(HAL_GPIO_ReadPin(GPIOD,GPIO_PIN_2));
        }

        if(d3)
        {
            handleMatrixKeyPress(r,3);
            while(HAL_GPIO_ReadPin(GPIOD,GPIO_PIN_3));
        }

        HAL_GPIO_WritePin(GPIOD, GPIO_PIN_4 << r, GPIO_PIN_RESET);
    }
}

/**
  * @brief Redraws only Display 2's description text for the currently
  *        highlighted coding method. Called on state entry and every time
  *        Up/Down changes the selection, so the description updates live
  *        before OK is pressed. Clears just the description's text block
  *        (not the whole Display 2 screen) to minimize flicker, the same
  *        principle used for Display 1's partial redraws.
  */
static void Redraw_Coding_Description(void)
{
  const uint16_t desc_y = 100;
  const uint16_t desc_h = 200; // generous block height for a wrapped 1-2 sentence description
  drawRectangle(&LCD2_PINS, prompt_x, desc_y, 480 - prompt_x, desc_h, 0x0000);
  printString(&LCD2_PINS, coding_options[coding_selection], prompt_x, prompt_y, 2, 0x07E0, 0x0000);
  printString(&LCD2_PINS, coding_descriptions[coding_selection], prompt_x, desc_y, 2, 0xFFFF, 0x0000);
}

/**
  * @brief Redraws only the message line region (used while typing). drawChar
  *        now paints background pixels in the same pass as the glyph, so
  *        there's no separate clear-then-draw flash — text is overwritten
  *        in place. The "> " marker column and one trailing blank cell are
  *        explicitly redrawn so a backspaced character's leftover pixels
  *        are always covered.
  */
static void Redraw_Message_Line(void)
{
  printString(&LCD1_PINS, message_buffer, msg_x, msg_y, msg_scale, 0xFFFF, 0x0000);
  // One extra blank cell past the current text end, to erase the
  // character that was just backspaced off (drawChar already paints its
  // own background, but only for characters printString actually visits).
  uint16_t end_x = msg_x + (uint16_t)strlen(message_buffer) * (6 * msg_scale);
  drawChar(&LCD1_PINS, ' ', end_x, msg_y, msg_scale, 0xFFFF, 0x0000);
}

/**
  * @brief Redraws only the coding-option list (used when the highlighted
  *        selection moves). drawChar paints its own background, so no
  *        separate clear pass is needed here either.
  */
static void Redraw_Coding_Options(void)
{
  uint16_t opt_y = 80;
  for (int8_t i = 0; i < 3; i++) {
    uint16_t color = (i == coding_selection) ? 0xFFE0 : 0xFFFF; // highlight selected in yellow
    // Always redraw the marker column so a previously-selected row's ">"
    // gets overwritten with a blank when selection moves away from it.
    printString(&LCD1_PINS, i == coding_selection ? ">" : " ", prompt_x, opt_y, 2, color, 0x0000);
    printString(&LCD1_PINS, coding_options[i], prompt_x + 20, opt_y, 2, color, 0x0000);
    opt_y += 40;
  }
}

/**
  * @brief Partial redraw of the probability entry rows on Display 1.
  *        Only updates the value column and cursor highlight, so there's
  *        no full-screen flash when the user types a digit.
  */
static void Redraw_Prob_Screen(void)
{
  static const char char_labels[5] = {'A','B','C','D','E'};
  char buf[16];
  uint16_t row_y = 60;

  for (uint8_t i = 0; i < 5; i++) {
    uint16_t label_color = (i == prob_cursor) ? 0xFFE0 : 0xFFFF; // yellow = active
    uint16_t val_color   = (i == prob_cursor) ? 0x07FF : 0xFFFF; // cyan for active value

    // Character label
    snprintf(buf, sizeof(buf), "%c:", char_labels[i]);
    printString(&LCD1_PINS, buf, 10, row_y, 2, label_color, 0x0000);

    // Value: if this is the active row show what is being typed, else show confirmed value
    if (i == prob_cursor) {
      snprintf(buf, sizeof(buf), "%3u%%   ", prob_current);
    } else {
      snprintf(buf, sizeof(buf), "%3u%%   ", prob_values[i]);
    }
    printString(&LCD1_PINS, buf, 60, row_y, 2, val_color, 0x0000);

    row_y += 42;
  }
}

// ============================================================
//  HUFFMAN TREE BUILDER
// ============================================================
void Build_Huffman_Tree(void)
{
  // Working array of active node indices, sorted by prob ascending
  int8_t active[MAX_NODES];
  uint8_t active_count = 5;

  // Create one leaf per symbol
  tree_node_count = 0;
  for (uint8_t i = 0; i < 5; i++) {
    tree_nodes[tree_node_count] = (TreeNode){-1,-1,-1,1,i,prob_values[i],0,0};
    active[i] = (int8_t)tree_node_count++;
  }

  // Sort active by prob ascending (simple insertion sort — only 5 items)
  for (uint8_t i = 1; i < active_count; i++) {
    int8_t key = active[i];
    int8_t j = (int8_t)i - 1;
    while (j >= 0 && tree_nodes[active[j]].prob > tree_nodes[key].prob) {
      active[j+1] = active[j]; j--;
    }
    active[j+1] = key;
  }

  // Iteratively combine two lowest-prob nodes
  while (active_count > 1) {
    int8_t l = active[0], r = active[1];
    uint16_t combined = tree_nodes[l].prob + tree_nodes[r].prob;
    int8_t parent_idx = (int8_t)tree_node_count;
    tree_nodes[parent_idx] = (TreeNode){l, r, -1, 0, 0xFF, combined, 0, 0};
    tree_nodes[l].parent = parent_idx;
    tree_nodes[r].parent = parent_idx;
    tree_node_count++;

    // Remove first two, insert new node in sorted position
    active_count -= 2;
    for (uint8_t k = 0; k < active_count; k++) active[k] = active[k+2];
    uint8_t pos = 0;
    while (pos < active_count && tree_nodes[active[pos]].prob <= combined) pos++;
    for (uint8_t k = active_count; k > pos; k--) active[k] = active[k-1];
    active[pos] = parent_idx;
    active_count++;
  }
  tree_root = active[0];
}

// ============================================================
//  SHANNON-FANO TREE BUILDER
// ============================================================
int8_t SF_Make_Node(uint8_t is_leaf, uint8_t symbol, uint16_t prob)
{
  int8_t idx = (int8_t)tree_node_count++;
  tree_nodes[idx] = (TreeNode){-1,-1,-1,is_leaf,symbol,prob,0,0};
  return idx;
}
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

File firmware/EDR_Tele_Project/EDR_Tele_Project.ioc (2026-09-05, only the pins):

Mcu.UserName=STM32H743VITx
PA8.Signal=GPIO_Output
PB0.Signal=GPIO_Output
PB1.Signal=GPIO_Output
PB12.Signal=GPIO_Output
PB2.Signal=GPIO_Output
PB5.Signal=GPIO_Output
PB6.Signal=GPIO_Output
PB7.Signal=GPIO_Output
PB8.Signal=GPIO_Output
PB9.Signal=GPIO_Output
PC5.Signal=GPIO_Output
PC6.Signal=GPIO_Output
PC7.Signal=GPIO_Output
PC8.Signal=GPIO_Output
PC9.Signal=GPIO_Output
PD0.Signal=GPIO_Input
PD1.Signal=GPIO_Input
PD10.Signal=GPIO_Output
PD11.Signal=GPIO_Output
PD12.Signal=GPIO_Output
PD13.Signal=GPIO_Output
PD14.Signal=GPIO_Output
PD15.Signal=GPIO_Output
PD2.Signal=GPIO_Input
PD3.Signal=GPIO_Input
PD4.Signal=GPIO_Output
PD5.Signal=GPIO_Output
PD6.Signal=GPIO_Output
PD7.Signal=GPIO_Output
PD8.Signal=GPIO_Output
PD9.Signal=GPIO_Output
PE10.Signal=GPIO_Output
PE11.Signal=GPIO_Output
PE12.Signal=GPIO_Output
PE13.Signal=GPIO_Output
PE14.Signal=GPIO_Output
PE15.Signal=GPIO_Output
PE7.Signal=GPIO_Output
PE8.Signal=GPIO_Output
PE9.Signal=GPIO_Output
